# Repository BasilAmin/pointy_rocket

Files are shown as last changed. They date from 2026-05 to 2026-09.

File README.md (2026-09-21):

# 🚀 Pointy Rocket V1

**Pointy Rocket** is an actively stabilised model-scale rocket developed by the Engineering Society of Castleknock College (SVCC). It uses **Thrust Vector Control (TVC)** — the same technique used in orbital-class rockets — to actively stabilise the vehicle in flight.

The project spans custom PCB hardware design, embedded flight firmware, and a high-fidelity physics simulation, all living in this repository.

---

> **An SVCC Project with support from RS Components**
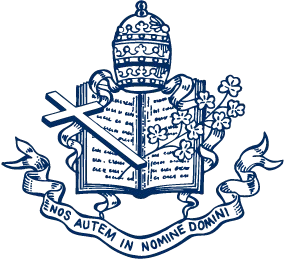
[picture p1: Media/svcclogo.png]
RS Logo
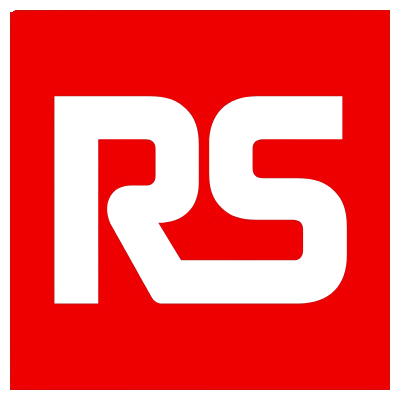
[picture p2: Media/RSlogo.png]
RS Logo
> &nbsp;&nbsp;&nbsp;&nbsp;&nbsp;&nbsp;&nbsp;&nbsp;&nbsp;&nbsp;&nbsp;&nbsp;

---

## Authors

- James Harcourt
- Basil Amin
- Ashkan Samali
- Feargal Browne
- Ben Liu
- Ryan Doran

---

## Project Overview

| Component | Details |
|---|---|
| Stabilisation | 2-axis Thrust Vector Control (TVC) via servo-gimballed motor mount  |
| Motors | 4× Estes D12 (clustered) |
| Microcontroller | Teensy 4.1 (NXP i.MX RT1062, Cortex-M7 @ 600 MHz) |
| IMU | MPU6050 (6-axis accelerometer + gyroscope, I2C) |
| Altimeter | MPL3115A2 barometric altimeter |
| Data Logging  | SD card (SPI) |
| Recovery | Parachute deployment |

---

## Repository Structure

```
pointy_rocket/
├── Dictator_Flight_Firmware/   # Main embedded flight firmware (Teensy 4.1 / PlatformIO)
├── Firmware_test/              # Firmware testing scripts and utilities
├── hardware/                   # KiCad PCB schematic & layout
│   └── pcb/
│       └── Pointy R1 Flight controller/
│           ├── *.kicad_sch
│           ├── *.kicad_pcb
│           ├── symbols.kicad_sym
│           └── footprints.pretty/
├── simulation/                 # Python flight simulation suite
│   ├── rocket_sim.py           # Full 6-DOF 3D simulation (RK4 + Quaternions)
│   ├── tvc_sim.py              # TVC-controlled flight engine
│   ├── rocketpy_engine.py      # RocketPy aerodynamics integration
│   ├── rocketpy_adapter.py     # Hybrid engine orchestrator
│   ├── motor_curve.py          # Thrust curve parser (.eng / .rse / .csv)
│   ├── motor_sweep.py          # Motor configuration parameter sweep
│   ├── gui_server.py           # Browser-based TVC simulator GUI
│   ├── plots.py                # Standalone matplotlib figure generator
│   ├── pygame_simulation.py    # Pygame visualisation
│   ├── requirements.txt
│   └── simulation_results.png
├── Media/                      # Logos and media assets
├── Pointy R1 Flight controller.csv  # BOM / component list
├── sim_specs.txt               # Simulation variable reference
└── .gitignore
```

---

## Firmware

The flight computer runs on a **Teensy 4.1**, programmed via PlatformIO with the Arduino framework. The firmware reads IMU data, runs a PID controller, and drives the two TVC servos in real time.

### Hardware

| Component | Details |
|---|---|
| Microcontroller | Teensy 4.1 (NXP i.MX RT1062, Cortex-M7 @ 600 MHz) |
| IMU | MPU6050 (6-axis accelerometer + gyroscope, I2C)  |
| Altimeter | MPL3115A2 barometric altimeter |
| Actuation | 2× Servo (dual-axis TVC gimbal) |
| Data Logging | SD card (SPI) |
| Power | AMASS XT60 connector |
| Ignition | N-MOSFET (D2PAK) motor ignition circuit |

### Dependencies

| Library | Version  |
|---|---|
| `arduino-libraries/Servo` | `^1.3.0` |
| `electroniccats/MPU6050`  | `^1.4.4` |
| `arduino-libraries/SD` | `^1.3.0` |

### Build & Flash

**Prerequisites:** [PlatformIO](https://platformio.org/) (CLI or VS Code extension)

```bash
# Clone the repo
git clone https://github.com/BasilAmin/pointy_rocket.git
cd pointy_rocket/Dictator_Flight_Firmware

# Build
pio run

# Flash to Teensy (press the button on the board if needed)
pio run --target upload

# Open serial monitor
pio device monitor
```

---

## Hardware / PCB

The custom flight controller PCB is designed in **KiCad** and lives in `hardware/pcb/Pointy R1 Flight controller/`. Custom symbols and footprints are included for:

- Teensy 4.1 (form-factor reference)
- MPU6050 breakout (GY-521 module)
- MPL3115A2 barometric altimeter
- AMASS XT60 power connector
- N-MOSFET (D2PAK) motor ignition circuit
- Tactile and slide switches
- Passive components (diode, SOT-23 transistor)

To open the design, install [KiCad 7+](https://www.kicad.org/) and open `Pointy R1 Flight controller.kicad_pro`.

---

## Simulation

The simulation suite models the full flight from ignition through parachute landing. It uses a hybrid approach combining the trusted aerodynamics of **RocketPy** with a custom in-house **TVC 6-DOF engine**.

### Architecture

Because Pointy Rocket is a finless TVC rocket (unstable by design), a purely passive simulation cannot fly it. The two engines are combined to play to each other's strengths:

- **RocketPy** (`rocketpy_engine.py`) provides trusted aerodynamics: Barrowman centre of pressure, static margin, a real atmosphere model. It cannot model thrust vectoring, so it cannot fly the rocket passively.
- **The in-house TVC sim** (`tvc_sim.py`) flies the actively steered rocket (quaternion 6-DOF, RK4, PID gimbal), using RocketPy's centre of pressure and drag values instead of a rough analytic estimate.

`rocketpy_adapter.py` orchestrates both and returns side-by-side results.

### Setup

```bash
cd simulation
python -m venv .venv && source .venv/bin/activate   # Windows: .venv\Scripts\activate
pip install -r requirements.txt
```

Requirements: `numpy`, `matplotlib`, `rocketpy` (which pulls in `scipy` and `netCDF4`).

### TVC Simulator GUI

A browser-based GUI wraps both flight engines and lets you upload or fetch motor files, import body geometry, and view results interactively.

```bash
cd simulation
python gui_server.py
```

Open `http://127.0.0.1:8765`. Each run renders a **matplotlib** figure (altitude, thrust curve, TVC gimbal angles, speed/mass) shown below the live chart with a PNG download link.

The same figure can be produced from the command line:

```bash
python plots.py path/to/motor.eng    # writes matplotlib_results.png
```

### Flight computer in the loop

The TVC sim does not steer with perfect knowledge — it runs a realistic flight-computer model (`flight_computer.py`) matched to the actual hardware (MPU6050 read at its ±2 g / ±250 °/s defaults; two servos on the Arduino `Servo` library = 1° write resolution):

- **MPU6050 sensor model** — per-flight gyro/accel bias, white noise, range clipping and 16-bit quantisation.
- **Attitude estimator** — gyro integration with on-pad calibration. (In flight a rocket's accelerometer can't sense gravity — under thrust it reads thrust, in coast it's in free fall — so the accelerometer is used only on the pad to set the initial attitude and the gyro bias. This is the reference algorithm for the Teensy firmware.)
- **Discrete PID** at the configured control rate with control-loop **latency**.
- **Servo model** — slew-rate limit, command resolution, deadband and lag.

Two findings this exposes: residual **gyro-bias drift** is the dominant attitude error, and because thrust vectoring needs thrust, the rocket is only controllable **during the burn** — after burnout a finless vehicle tumbles (expected; recovery is by parachute). Stability is therefore judged over the powered phase.

### Monte-Carlo dispersion

`montecarlo.py` runs many flights with the uncertain parameters perturbed (mass, propellant, motor thrust, drag, centre of pressure, wind, thrust misalignment, sensor bias/noise) and reports the distribution of apogee, powered-phase tilt, gimbal usage and landing radius, plus the fraction of flights that stay controlled during burn. RocketPy aerodynamics are evaluated once for the nominal vehicle; flights run in parallel across CPU cores.

```bash
python montecarlo.py path/to/motor.eng 200 path/to/rocket.ork
```

### 6-DOF Flight Simulation

`rocket_sim.py` implements a full **6 Degrees of Freedom** rigid-body simulation:

- **RK4 numerical integration** for accurate state propagation
- **Quaternion-based attitude representation** (no gimbal lock)
- **PID controller** for dual-axis TVC stabilisation
- **Dynamic mass model** — propellant mass decreases with cumulative impulse
- **High-fidelity D12 thrust curve** (4× scaled cluster, from verified RASP data)
- **Aerodynamic drag** with wind shear model
- **Automatic parachute deployment** on descent

#### PID Controller Parameters

| Gain | Value |
|---|---|
| Kp | 0.8 |
| Kd | 1.5 |
| Ki | 0 |
| Max gimbal angle | ±8° |

```bash
python rocket_sim.py
```

Outputs a 4-panel plot (`simulation_results.png`) showing:

- 3D flight trajectory
- Altitude vs. time
- Dual-axis TVC gimbal angles
- Dynamic mass and thrust profile

### Motor Configuration Sweep

`motor_sweep.py` sweeps across 1–4 motor configurations to compare predicted performance across different cluster sizes.

```bash
python motor_sweep.py
```

---

## Language Breakdown

| Language | Share  |
|---|---|
| C++ | 81.2%  |
| Python | 9.7% |
| C | 6.0% |
| JavaScript | 1.2% |
| Processing | 0.9% |
| HTML | 0.6% |
| Other | 0.4% |

---

## License

MIT License — © 2026 Basil Amin. See [LICENSE](firmware/LICENSE) for details.
## License

MIT License — © 2026 Basil Amin. See [LICENSE](firmware/LICENSE) for details.

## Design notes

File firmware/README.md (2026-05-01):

# Pointy Rocket V1

## Introduction
### Pointy Rocket (V1) is an actively controlled model scale rocket developed by the Engineering Society of Castleknock College. The rocket uses a conventional aerospace technique, known as thrust vectoring, to stablize the rocket. 

## PROJECT COMPONENTS:
1. Avionics System
2. TVC
3. Airframe
4. Simulation
5. Documentation
6. Software/Firmware

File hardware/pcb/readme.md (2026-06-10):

# Pointy R1 Flight Controller PCB

Custom flight controller board designed in KiCad for the Pointy R1 rocket. Handles motor control, sensor fusion, audio/visual feedback, and power regulation.

## Directory Structure

```
Pointy R1 Flight controller/
├── Pointy R1 Flight controller.kicad_pro   # KiCad project file
├── Pointy R1 Flight controller.kicad_sch   # Schematic
├── Pointy R1 Flight controller.kicad_pcb   # PCB layout
├── Pointy R1 Flight controller.csv         # Bill of materials
├── 3d Models/                              # STEP files for 3D viewer
└── Pointy R1 Flight controller-backups/    # KiCad auto-backups
```

## Bill of Materials

| Ref | Qty | Part | Description |
|-----|-----|---|---|
| IC1 | 1 | Teensy 4.1 | Main microcontroller |
| U2 | 1 | GY-521 (MPU-6050) | 6-axis IMU (accel + gyro) |
| U3 | 1 | MPL3115A2 | Barometric pressure / altitude sensor |
| U1 | 1 | L7805CV | 5V linear voltage regulator (TO-220) |
| Q1, Q2, Q3 | 3 | IRLZ44NSTRLPBF | N-channel MOSFET for motor/actuator control |
| D1 | 1 | 1N5822 | Schottky diode (flyback protection) |
| D2, D3, D4 | 3 | 1N4007 | Rectifier diodes |
| M1, M2 | 2 | Servo header | 3-pin 2.54 mm servo connectors |
| P1–P4 | 4 | 282837-2 | 2-pos screw terminals (TE Connectivity) |
| J3 | 1 | XT60-M | Main battery connector |
| LED1 | 1 | COM-16347 | RGB LED (SparkFun) |
| LS1 | 1 | CMI-1295-0585T | Piezo buzzer |
| S2 | 1 | TS02-66-70-BK-100-LCR-D | Tactile push button |
| C1 | 1 | 10 µF | Bulk decoupling (0805) |
| C2 | 1 | 1 µF | Mid-frequency decoupling (0805) |
| C3 | 1 | 100 nF | High-frequency decoupling (0805) |
| R2, R3, R5, R7 | 4 | 470 Ω | Current-limiting resistors (0805) |
| R8 | 1 | 10 kΩ | Pull-up/pull-down resistor (0805) |
| R9 | 1 | 4.7 kΩ | Pull-up/pull-down resistor (0805) |

## Design Notes

- **Power input:** XT60 connector → L7805CV regulates down to 5 V for logic. Teensy 4.1 runs at 3.3 V internally.
- **Motor/actuator outputs:** Three IRLZ44N logic-level MOSFETs switch inductive loads; flyback diodes (1N4007) on each gate, 1N5822 on the rail.
- **IMU:** GY-521 module (MPU-6050) connected via I2C for attitude estimation.
- **Altimeter:** MPL3115A2 on I2C for altitude and vertical speed.
- **Feedback:** RGB LED and piezo buzzer for status/alarm indication.
- **Programming:** Teensy 4.1 programs over USB; no additional programmer needed.
- **PCB has passed DFM review** — Gerbers ready for manufacture (see git history).

## Opening the Project

Requires **KiCad 7+**. Open `Pointy R1 Flight controller/Pointy R1 Flight controller.kicad_pro`.

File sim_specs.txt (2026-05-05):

Fundamental Simulation variables:
- Velocity
- Vertical Velocity
- Horizontal Velocity
- Vertical displacement
- Horizontal displacement
- Gravitational constant (9.802m/s^2)
- Time elapsed/Time taken
- Acceleration
- Mass
- Initial Thrust Force
- Normal Thrust Force
- Motor Burn Time

This is excluding the control system and strictly considers a point mass being propelled up. It does not really take much into consideration but is fundamental

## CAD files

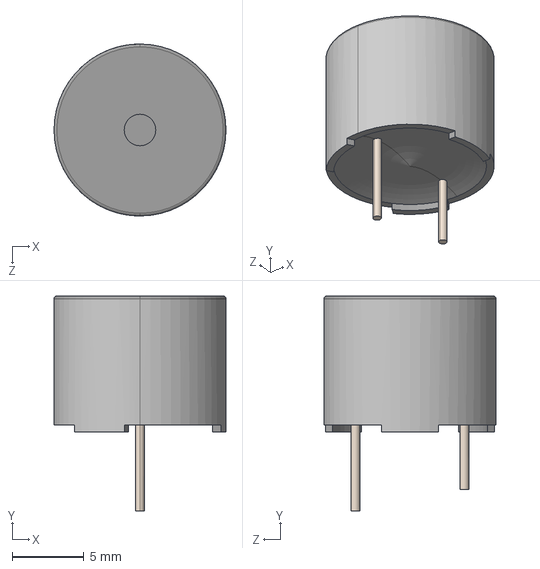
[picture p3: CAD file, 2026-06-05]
hardware/pcb/Pointy R1 Flight controller/3d Models/CMI-1295-0585T--3DModel-STEP-1.STEP
12.0 x 15.0 x 12.0 mm

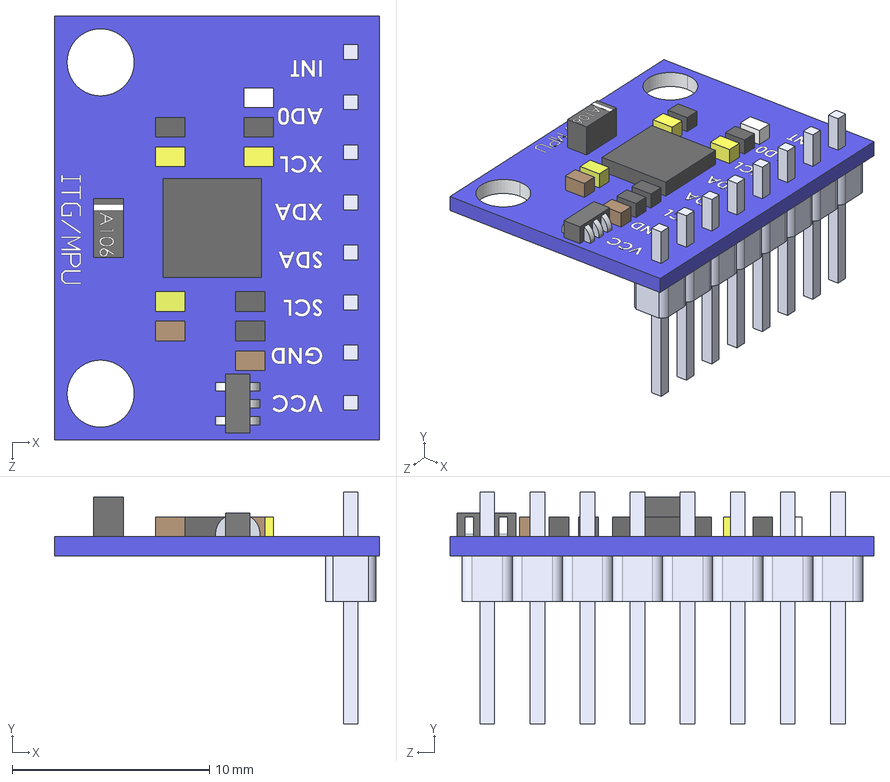
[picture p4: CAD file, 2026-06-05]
hardware/pcb/Pointy R1 Flight controller/3d Models/itg-mpu-gy-521-1.snapshot.16/ITG-MPU.STEP
16.5 x 11.8 x 21.5 mm
8 Header-Pin
Placa_Base

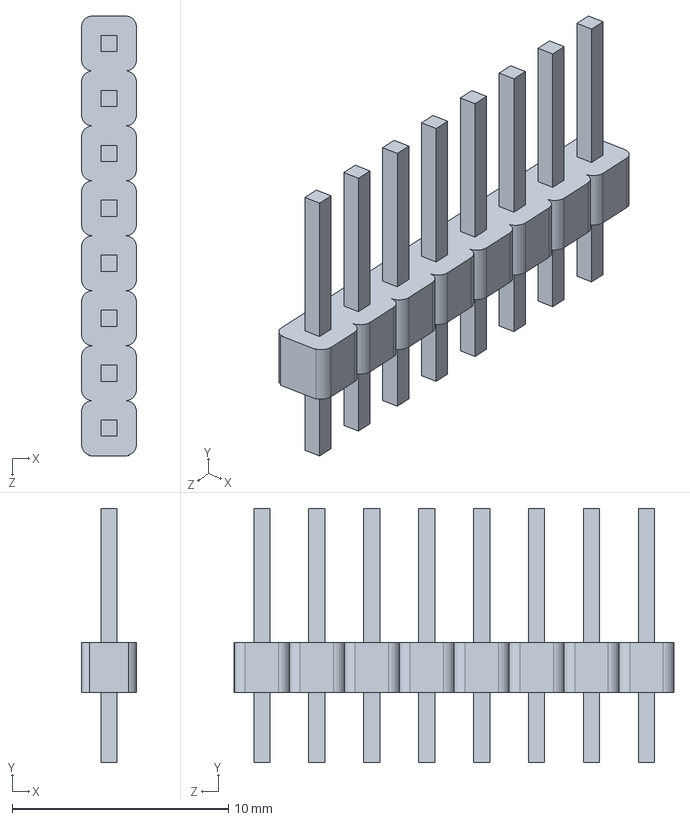
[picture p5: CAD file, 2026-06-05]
hardware/pcb/Pointy R1 Flight controller/3d Models/itg-mpu-gy-521-1.snapshot.16/Partes/8 Header-Pin.SLDPRT
2.54 x 11.8 x 20.3 mm

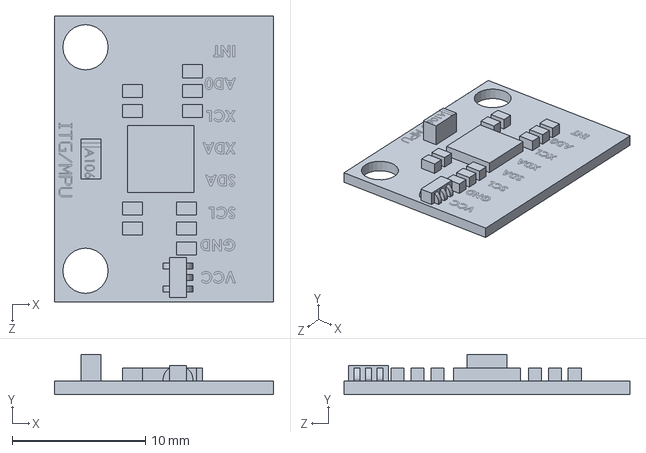
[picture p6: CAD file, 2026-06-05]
hardware/pcb/Pointy R1 Flight controller/3d Models/itg-mpu-gy-521-1.snapshot.16/Partes/Placa_Base.SLDPRT
16.5 x 3.01 x 21.5 mm

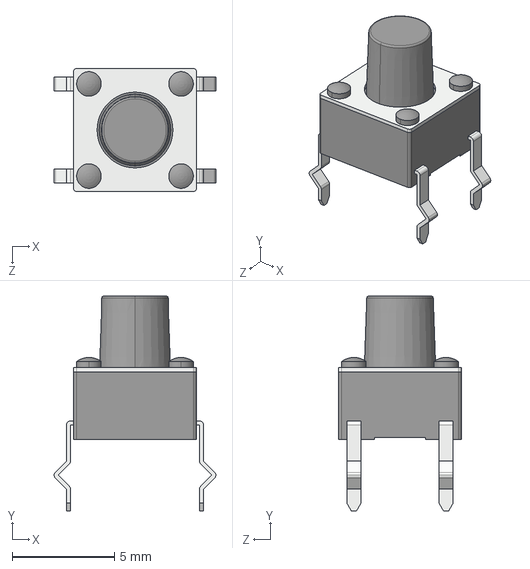
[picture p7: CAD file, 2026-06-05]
hardware/pcb/Pointy R1 Flight controller/3d Models/TS02-66-70-BK-100-LCR-D--3DModel-STEP-242080.STEP
7.90 x 10.5 x 6.00 mm

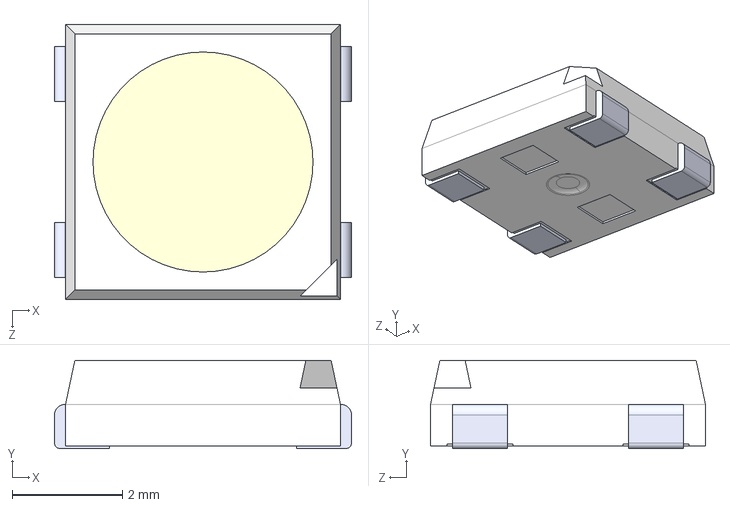
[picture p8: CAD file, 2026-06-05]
hardware/pcb/Pointy R1 Flight controller/3d Models/2758--3DModel-STEP-56544.STEP
5.40 x 1.60 x 5.00 mm

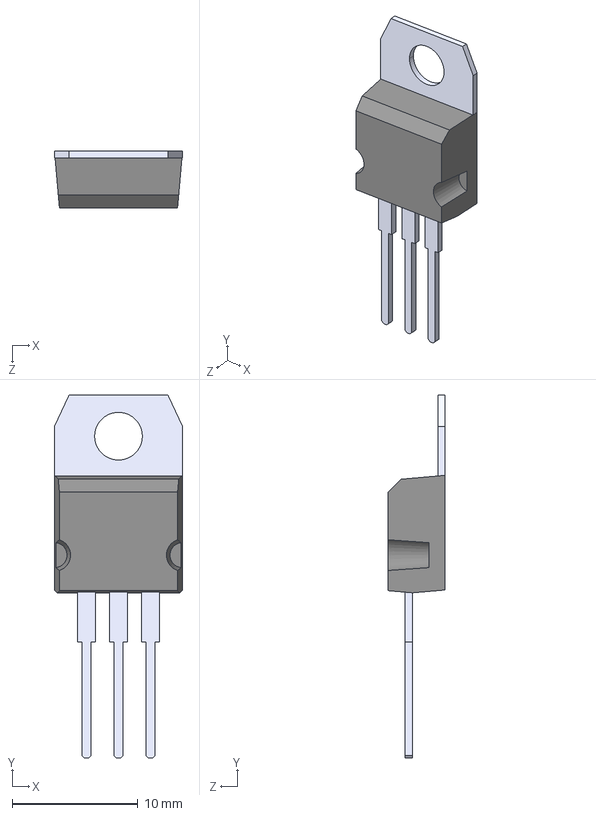
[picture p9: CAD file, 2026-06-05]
hardware/pcb/Pointy R1 Flight controller/3d Models/L7805CV.STEP
10.2 x 28.9 x 4.50 mm

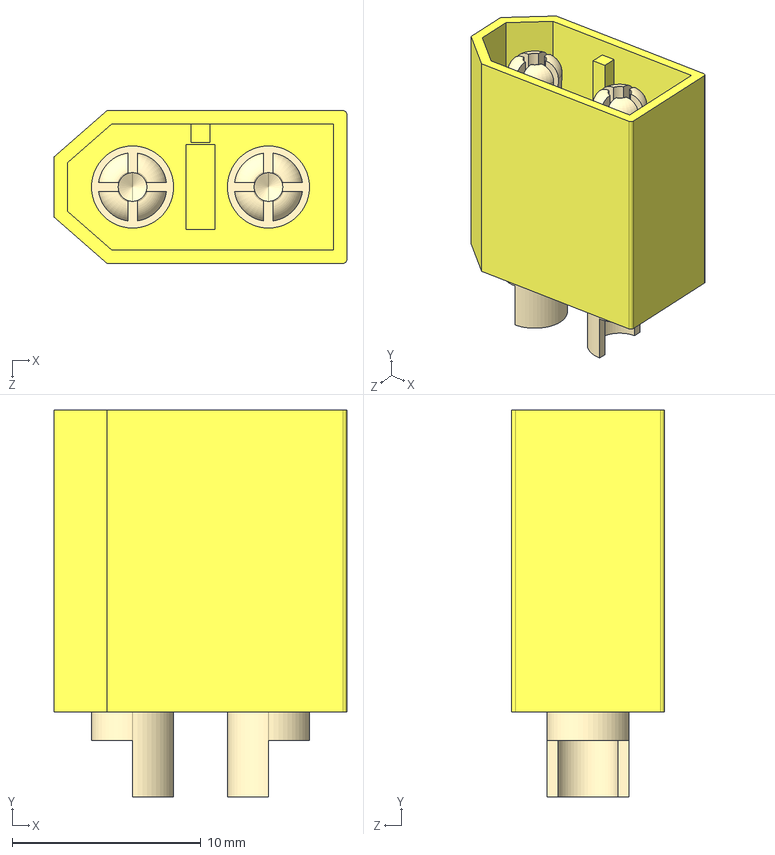
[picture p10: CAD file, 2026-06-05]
hardware/pcb/Pointy R1 Flight controller/3d Models/XT60 YELLOW--3DModel-STEP-269445.STEP
15.5 x 20.5 x 8.10 mm

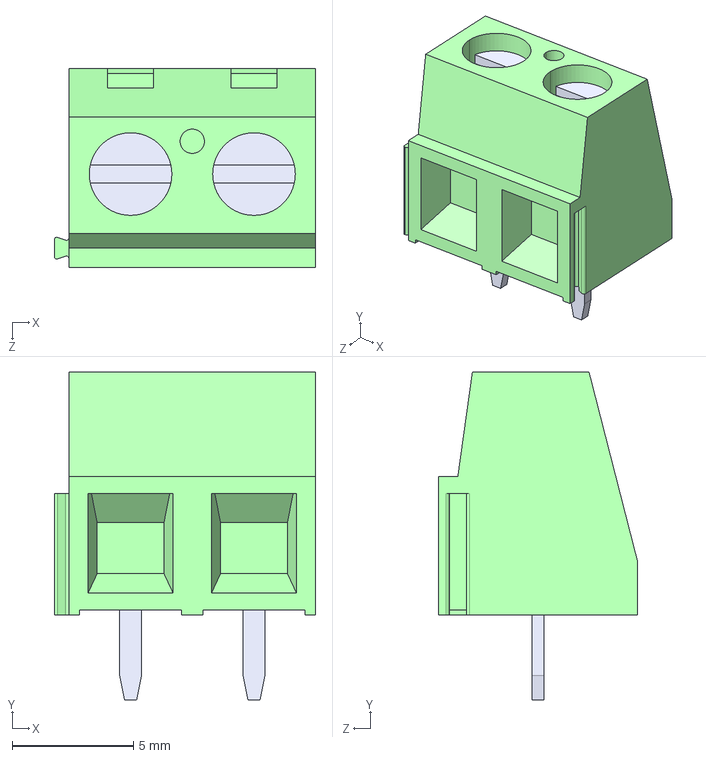
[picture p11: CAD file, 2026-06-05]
hardware/pcb/Pointy R1 Flight controller/3d Models/282837-2--3DModel-STEP-269445.STEP
10.8 x 13.5 x 8.20 mm

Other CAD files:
hardware/pcb/Pointy R1 Flight controller/3d Models/itg-mpu-gy-521-1.snapshot.16/ITG-MPU.SLDASM

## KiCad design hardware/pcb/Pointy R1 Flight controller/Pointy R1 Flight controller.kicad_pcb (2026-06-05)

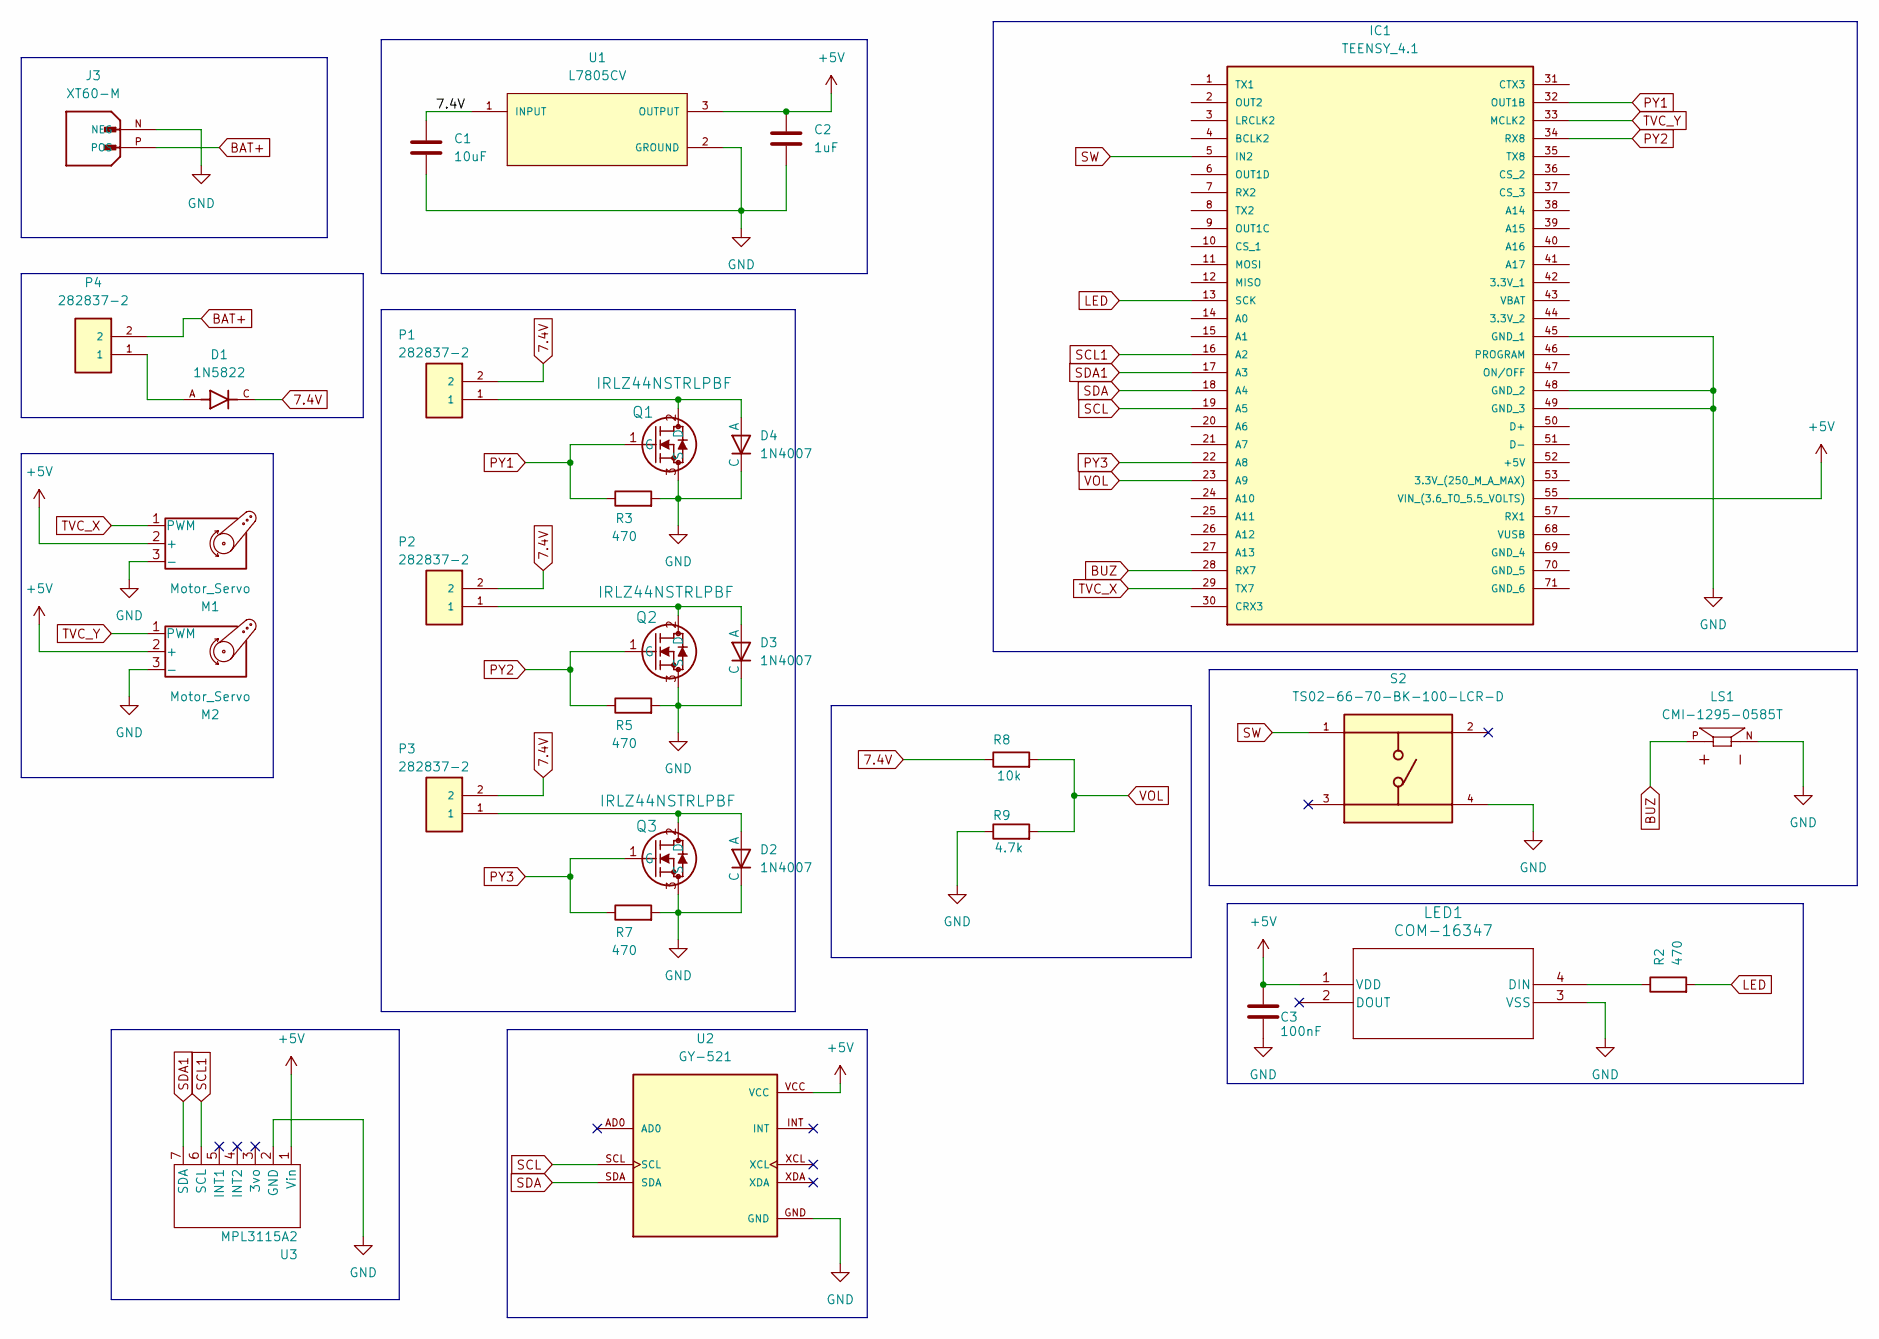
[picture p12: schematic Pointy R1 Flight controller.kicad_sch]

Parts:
C1: 10uF; C_0805_2012Metric
C2: 1uF; C_0805_2012Metric
C3: 100nF; C_0805_2012Metric
D1: 1N5822; DIOAD1990W125L900D530; PARTREV K2105
D2, D3, D4: 1N4007; P1_DO-41
IC1: TEENSY_4.1; TEENSY41; Manufacturer_Part_Number TEENSY 4.1
J3: XT60-M; AMASS_XT60-M; PARTREV V1.2
LED1: COM-16347; COM-16347_SPK
LS1: CMI-1295-0585T; CUI_CMI-1295-0585T; PARTREV N/A
M1, M2: Motor_Servo; PinHeader_1x03_P2.54mm_Vertical
P1, P2, P3, P4: 282837-2; TE_282837-2; PARTREV G3
Q1, Q2, Q3: IRLZ44NSTRLPBF; NMOSGDS_D2PAK_INF
R2, R3, R5, R7: 470; R_0805_2012Metric
R8: 10k; R_0805_2012Metric
R9: 4.7k; R_0805_2012Metric
S2: TS02-66-70-BK-100-LCR-D; SW_TS02-66-70-BK-100-LCR-D; PARTREV 1.0
U1: L7805CV; TO255P1040X460X1968-3; PARTREV 36
U2: GY-521; MODULE_GY-521; PARTREV NA
U3: MPL3115A2

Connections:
7.4V: C1.1, D1.C, P1.2, P2.2, P3.2, R8.1, U1.1 (INPUT)
+5V: C2.1, C3.1, IC1.55 (VIN_(3.6_TO_5.5_VOLTS)), LED1.1 (VDD), M1.2 (+), M2.2 (+), U1.3 (OUTPUT), U2.VCC, U3.1 (Vin)
BAT+: J3.P (POS), P4.2
BUZ: IC1.28 (RX7), LS1.P
GND: C1.2, C2.2, C3.2, D2.2 (C), D3.2 (C), D4.2 (C), IC1.45 (GND_1), IC1.48 (GND_2), IC1.49 (GND_3), J3.N (NEG), LED1.3 (VSS), LS1.N, M1.3 (-), M2.3 (-), Q1.3 (S), Q2.3 (S), Q3.3 (S), R3.2, R5.2, R7.2, R9.1, S2.4, U1.2 (GROUND), U2.GND, U3.2 (GND)
LED: IC1.13 (SCK), R2.2
unnamed: D1.A, P4.1
unnamed: D2.1 (A), P3.1, Q3.2 (D)
unnamed: D3.1 (A), P2.1, Q2.2 (D)
unnamed: D4.1 (A), P1.1, Q1.2 (D)
unnamed: LED1.4 (DIN), R2.1
PY1: IC1.32 (OUT1B), Q1.1 (G), R3.1
PY2: IC1.34 (RX8), Q2.1 (G), R5.1
PY3: IC1.22 (A8), Q3.1 (G), R7.1
SCL: IC1.19 (A5), U2.SCL
SCL1: IC1.16 (A2), U3.6 (SCL)
SDA: IC1.18 (A4), U2.SDA
SDA1: IC1.17 (A3), U3.7 (SDA)
SW: IC1.5 (IN2), S2.1
TVC_X: IC1.29 (TX7), M1.1 (PWM)
TVC_Y: IC1.33 (MCLK2), M2.1 (PWM)
VOL: IC1.23 (A9), R8.2, R9.2

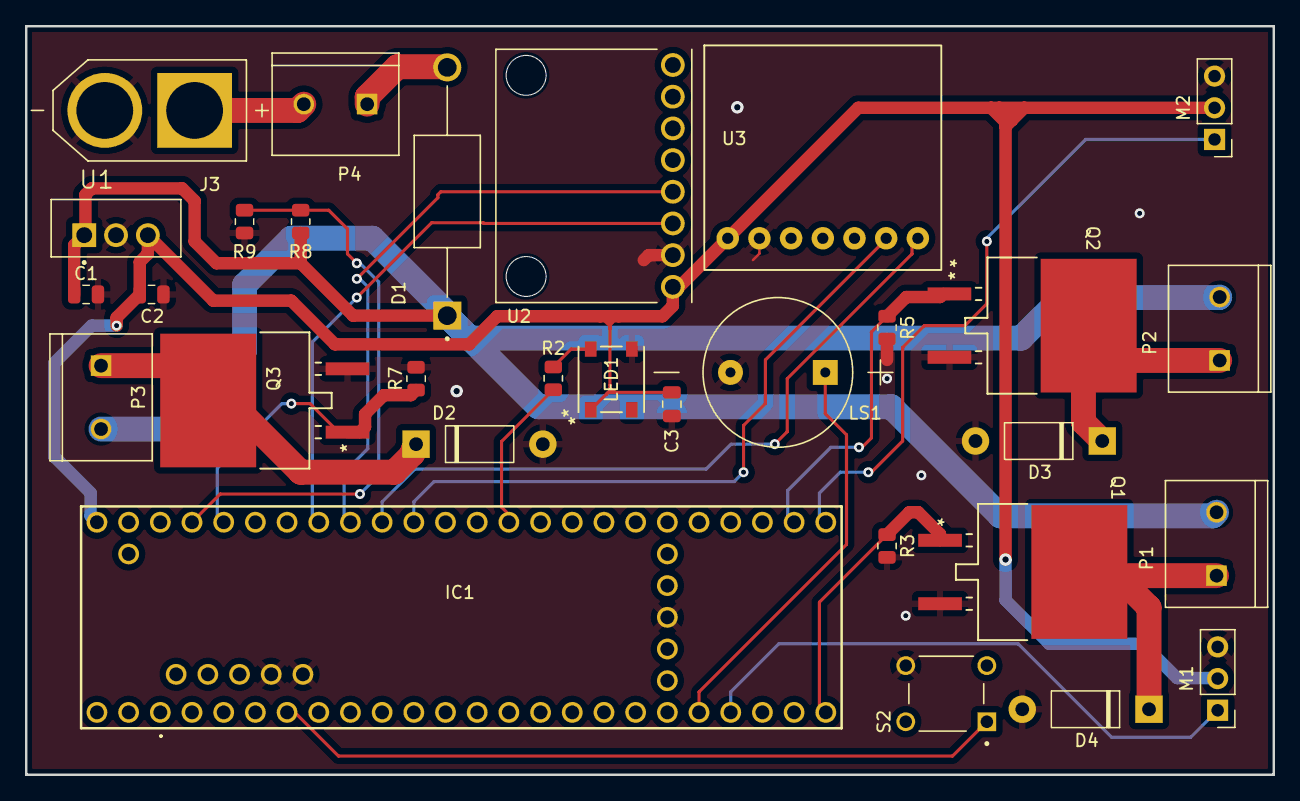
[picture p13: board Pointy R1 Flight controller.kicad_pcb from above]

Board: 2 copper layers, 100.0 x 60.0 mm, 30 parts (0 on the bottom side), 22 nets.

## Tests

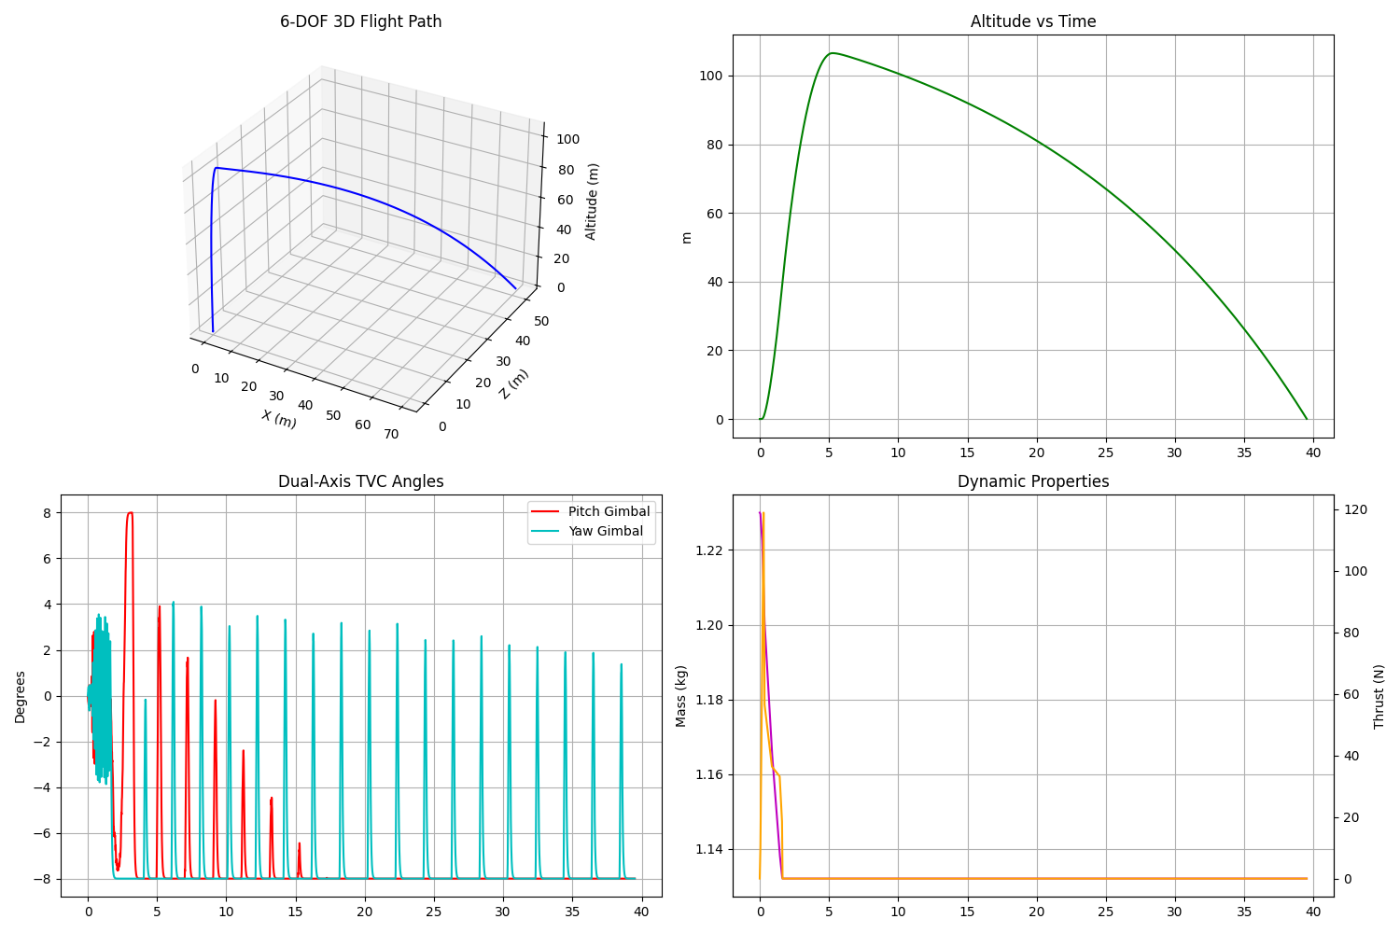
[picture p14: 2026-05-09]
simulation/simulation_results.png

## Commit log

2026-05-02 pcb env set up
    [Untitled.kicad_pcb, Untitled.kicad_sch]
2026-05-02 create hardware and pcb development env
    [Pointy R1 Flight controller.kicad_pcb, Pointy R1 Flight controller.kicad_sch]
2026-05-03 create PCB library env, added main components to sch
    [Pointy R1 Flight controller.kicad_sch]
2026-05-04 created symbol and schematic for MPL3115A2
2026-05-04 added majority of power connections + buses, wired MPL3115A2 altimeter and gy-521 imu
    [Pointy R1 Flight controller.kicad_sch]
2026-05-04 added servos, pyro channels, voltage divider, switch, led, buzzer and xt60 connector. Made all connections
    [Pointy R1 Flight controller.kicad_sch]
2026-05-05 Connected voltage divider + removed floating Capacitors
    [Pointy R1 Flight controller.kicad_sch]
2026-05-05 added schottky diode for reverse polarity protection, neatened +formated sch
    [Pointy R1 Flight controller.kicad_sch]
2026-05-08 fix: invert TVC PID controller polarity and set vertical launch angle
2026-05-08 Add motor parameter sweep script
2026-05-08 Implement RK4 integration and Kalman Filter (Phase 1 & 2)
2026-05-08 Implement RK4 physics, synthetic IMU, and Kalman Filter
    Core physics and control upgrades:
    - Replaced unstable Forward Euler integration with a 4th-Order Runge-Kutta
    (RK4) solver, preventing artificial energy drift during high-frequency
    oscillations.
    - Introduced continuous-time actuator modeling (servo lag) via a first-order
    differential equation, making TVC dynamics independent of frame rate.
    - Implemented a synthetic IMU model that calculates Proper Acceleration to
    simulate realistic accelerometer distortion/swamping under high G-loads,
    along with gyroscope drift and Gaussian white noise.
    - Integrated a discrete-time 1D Kalman Filter to dynamically fuse the noisy
    IMU dat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
2026-05-08 Implementing dynamic mass, shifting CG, and realistic thrust curves
    This replaces the static mass and simple step-function thrust with a fully dynamic model. The simulation now parses a realistic thrust curve and couples propellant mass loss directly to the accumulated impulse. As propellant burns, the Center of Gravity accurately shifts forward and the Moment of Inertia decreases, altering the torque moment arms for the TVC and aerodynamic forces continuously throughout the burn.
2026-05-08 Implementing Phase 4: Wind shear and relative aerodynamics
    Added a horizontal wind profile that increases with altitude. The physics engine now calculates aerodynamic forces based on the rocket's velocity relative to the airmass rather than the ground frame, introducing realistic weathercocking torques. Also added an Integral (I) term to the TVC controller to help eliminate steady-state error caused by the continuous wind disturbance.
2026-05-09 Added decoupling cap to WS2812b
    [Pointy R1 Flight controller.kicad_sch]
2026-05-09 Replaced mosfets with higher current rated IRLZ44N
    [Pointy R1 Flight controller.kicad_sch]
2026-05-09 Added 1N4007 flyback diodes for over voltage/current protection on mosfets
    [Pointy R1 Flight controller.kicad_sch]
2026-05-09 Added 1N4007 flyback diodes to schematic + made neccisary connections
    [Pointy R1 Flight controller.kicad_sch]
2026-05-10 Created .pcb document, pcb outline and placed all components on the board
    [Pointy R1 Flight controller.kicad_pcb]
2026-05-13 Add files via upload
    Live simulation for making the PID controller, currently no turbulence or PID controller. Also torque is probably calculated wrong
2026-05-13 Routed majority of traces for all components, excluding minor power management and gnd plane tasks
    [Pointy R1 Flight controller.kicad_pcb, Pointy R1 Flight controller.kicad_sch]
2026-05-13 Completed routing and added gnd plane, completeting v1 of the PFC - ready for drm
    [Pointy R1 Flight controller.kicad_pcb, Pointy R1 Flight controller.kicad_sch]
2026-05-14 Fixed various issues on PCB, genrated gbr files - ready for dfm
    [Pointy R1 Flight controller-B_Cu.gbl, Pointy R1 Flight controller-B_Mask.gbs, Pointy R1 Flight controller-B_Paste.gbp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]
2026-05-14 Generated Gerber zip file
    [Pointy R1 Flight controller.kicad_pcb]
2026-05-16 Ran DFM + updated pcb accordingly. New gbr files generated
    [Pointy R1 Flight controller-B_Cu.gbl, Pointy R1 Flight controller-B_Mask.gbs, Pointy R1 Flight controller-B_Paste.gbp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]
2026-06-05 Added 3d Models to PCB for teensy + Mosfets
    [2758--3DModel-STEP-56544.STEP, 282837-2--3DModel-STEP-269445.STEP, 8 Header-Pin.SLDPRT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]
2026-06-10 create PCB readme
